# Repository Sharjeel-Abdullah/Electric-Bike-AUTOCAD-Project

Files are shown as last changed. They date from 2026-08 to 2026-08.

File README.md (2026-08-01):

# Electric-Bike-AUTOCAD-Project
Complete engineering layout, CAD drawing files, and manufacturing cost analysis for a 2 kW Electric Bike assembly.
# Electric Bike Assembly Design

A complete CAD assembly, mechanical layout, and cost analysis for a commuter electric bike designed in **AutoCAD**.

---

## 📌 Features & Contents

* **AutoCAD Assembly:** Complete 2D/3D `.dwg` drawings for the chassis, motor mounts, and component packaging.
* **Cost Estimation:** Itemized Bill of Materials (BOM) including component pricing and material selection.
* **Design Renders:** Visual preview sheets and exported CAD renders for quick viewing.

---

## 📁 Repository Structure

```text
--> README.md               # Project documentation
--> Electric Bike Project   # Whole Project
  -->Assembly               # Contains the AUTOCAD File + Screenshots to preview the project
  -->Documentation          # Complete Report + Cost Estimation

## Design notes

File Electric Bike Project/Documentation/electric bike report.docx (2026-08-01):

DESIGN AND DEVELOPMENT OF

ELECTRIC BIKE

[Project Report]

ABSTRACT

The increasing demand for sustainable transportation, rising fuel costs and growing environmental concerns have accelerated the development of electric vehicles as an efficient alternative to conventional fuel-powered transportation. This project presents the design and development of an Electric Bike that provides an economical, environment friendly and energy-efficient solution for short and medium-distance travel purpose. The proposed system integrates a Brushless DC (BLDC) motor powered by a lithium-ion battery pack, offering high efficiency, low maintenance and reliable performance.

The electric bike is designed with a lightweight yet durable frame that accommodates the battery pack, motor, controller, and other essential electrical components while maintaining proper weight distribution and rider comfort. A high-performance BLDC motor is selected to deliver smooth acceleration and a maximum speed suitable for urban transportation. The lithium-ion battery provides sufficient energy storage to achieve an extended driving range on a single charge while reducing charging frequency and operating costs.

The vehicle incorporates an LCD display that provides real-time information, including speed, battery level, trip distance and other operational parameters, enabling the rider to monitor the system effectively. For enhanced safety, the bike is equipped with Brembo hydraulic disc brakes, providing reliable braking performance under various riding conditions. The suspension system consists of hydraulic telescopic front forks and adjustable rear shock absorbers, ensuring improved ride comfort, vehicle stability and effective vibration damping on uneven road surfaces.

The design process includes component selection, system modeling, mechanical layout, electrical integration and performance analysis to ensure efficient operation and structural reliability. The completed design demonstrates the practical application of electric vehicle technology by combining efficiency, safety, durability, and rider comfort within a compact two-wheeled platform. This project highlights the potential of electric bikes as a sustainable mode of transportation capable of reducing fuel consumption, lowering greenhouse gas emissions and minimizing maintenance costs while meeting the daily mobility requirements of modern society.

TABLE OF CONTENTS:

Sr No. | TOPICS | Page No.
1. | OBJECTIVES | 4
2. | PROBLEMS | 5-6
3. | PROPOSED SOLUTIONS | 7-10
4. | COMPONENTS AND MATERIALS USED WITH SPECIFICATIONS | 10-16
5. | DESIGN CALCULATIONS | 17-23
6. | FABRICATION PROCESS | 23
7. | ASSEMBLY PROCESS | 23
8. | WORKING PRINCIPLE | 24
9. | COST ESTIMATION | 24-25
10. | LIMITATIONS OF THE PROPOSED MODEL | 25-26
11. | CONCLUSION | 26
12. | CAD MODEL AND ASSEMBLY | 27-28
13. | REFERENCES | 29

1) Objectives
- Design and develop an electric bike capable of safely carrying two adult riders with a strong and durable frame.
- Select a 2 kW BLDC motor and a 60 V lithium-ion battery to achieve a maximum speed of approximately 50 km/h with efficient power delivery.
- Integrate an efficient electrical drive system comprising the BLDC motor, motor controller, battery management system (BMS), and throttle for smooth and reliable operation.
- Equip the bike with a multifunction LCD display to provide real-time information such as speed, battery level, and trip distance.
- Enhance rider safety by incorporating Brembo hydraulic disc brakes and a hydraulic suspension system for superior braking performance and riding comfort.
- Evaluate the bike's performance in terms of speed, load-carrying capacity, battery range, structural stability, and overall efficiency to ensure compliance with the design objectives.
2) PROBLEMS

The transportation sector is one of the largest contributors to fuel consumption and environmental pollution. Conventional fuel-powered motorcycles, although widely used, suffer from several drawbacks related to efficiency, operating cost, and environmental impact. Likewise, many existing electric bikes available in the market utilize low-cost components that compromise performance, reliability, and rider comfort. These limitations motivated the development of the proposed electric bike using an optimized combination of modern electrical and mechanical components.

Problems Associated with Fuel-Based Motorcycles

1. High Fuel Consumption

Conventional motorcycles rely on petrol or diesel, whose prices continue to increase over time. Daily commuting results in significant fuel expenses, making transportation costly for users.

2. Environmental Pollution

Internal combustion engines emit harmful gases such as carbon dioxide (CO₂), carbon monoxide (CO), nitrogen oxides (NOₓ), and unburned hydrocarbons, contributing to global warming and air pollution.

3. High Maintenance Requirements

Fuel-powered engines consist of numerous moving parts that require regular servicing, including engine oil replacement, spark plug maintenance, clutch adjustments, air filter cleaning, and exhaust system servicing.

4. Low Energy Efficiency

A large portion of the fuel's energy is lost as heat through the engine and exhaust system, resulting in comparatively lower overall efficiency than electric propulsion systems.

5. Noise and Vibration

Combustion engines generate considerable noise and vibration, reducing rider comfort and contributing to noise pollution in urban environments.

6. Dependence on Fossil Fuels

Fuel-powered motorcycles rely entirely on non-renewable fossil fuels, making them unsustainable as fuel resources continue to diminish.

Problems Found in Many Existing Electric Bikes

Although electric bikes eliminate many of the disadvantages of fuel-powered motorcycles, several commercially available low-cost electric bikes still exhibit notable limitations.

1. Use of Brushed DC Motors

Many entry-level electric bikes employ brushed DC motors due to their lower initial cost. However, these motors have brushes that wear over time, require frequent maintenance, generate heat, and operate with lower efficiency.

2. Lead-Acid Batteries

Some electric bikes continue to use lead-acid batteries because of their low purchase price. These batteries are heavy, have lower energy density, longer charging times, shorter service life, and provide limited travel range.

3. Basic Mechanical Braking Systems

Low-cost electric bikes often use mechanical drum or cable-operated disc brakes, which offer lower braking performance and require frequent adjustment compared to hydraulic braking systems.

4. Conventional Suspension Systems

Basic spring suspension provides limited vibration damping and reduced comfort, especially when traveling on uneven roads or carrying additional load.

5. Lack of Smart Monitoring

Many economical electric bikes lack digital displays, preventing riders from monitoring battery percentage, speed, trip distance, and system status accurately.

6. Reduced Performance

The combination of low-capacity batteries and lower-efficiency motors often results in reduced acceleration, lower maximum speed, and shorter travel distance per charge.

3) PROPOSED SOLUTION

To overcome the limitations of conventional motorcycles and existing electric bikes, the proposed electric bike incorporates a carefully selected combination of electrical and mechanical components that improve efficiency, safety, reliability, and rider comfort.

1. BLDC Motor Instead of a Brushed DC Motor

A Brushless DC (BLDC) motor is selected as the propulsion system due to its superior performance and efficiency.

Brushed DC Motor | BLDC Motor (Selected)
Brushes wear out with time | Brushless construction eliminates wear
Requires regular maintenance | Virtually maintenance-free
Lower efficiency | Higher efficiency (typically 85–95%)
Generates more heat | Better thermal performance
Shorter lifespan | Longer operational life
Lower torque | Higher torque-to-weight ratio

Reason for Selection:
The BLDC motor offers higher efficiency, smoother operation, reduced maintenance, and longer service life, making it ideal for electric vehicles.

2. Lithium-Ion Battery Instead of Lead-Acid Battery

The proposed bike uses a Lithium-Ion battery pack rather than a lead-acid battery.

Lead-Acid Battery | Lithium-Ion Battery (Selected)
Heavy | Lightweight
Lower energy density | Higher energy density
Shorter lifespan | Longer cycle life
Slow charging | Faster charging
Higher maintenance | Maintenance-free
Lower travel range | Greater travel range

Reason for Selection:
Lithium-ion batteries significantly reduce vehicle weight while increasing range, charging efficiency, and overall battery life.

3. Hydraulic Brembo Disc Brakes Instead of Mechanical Brakes

For the braking system, Brembo hydraulic disc brakes are employed.

Mechanical Brakes | Brembo Hydraulic Disc Brakes (Selected)
Higher braking effort | Lower lever effort
Less precise braking | Excellent braking control
Requires cable adjustment | Self-adjusting hydraulic system
Reduced stopping performance | Superior stopping power

Reason for Selection:
Hydraulic disc brakes provide shorter stopping distances, improved safety, and consistent braking performance in both dry and wet conditions.

4. Hydraulic Suspension Instead of Conventional Spring Suspension

The proposed bike utilizes hydraulic telescopic front forks and adjustable rear hydraulic shock absorbers.

Conventional Suspension | Hydraulic Suspension (Selected)
Limited damping | Excellent vibration damping
Reduced comfort | Improved ride comfort
Less stability | Better handling and stability
Lower adaptability | Adjustable for varying road conditions

Reason for Selection:
Hydraulic suspension enhances rider comfort, minimizes vibration, and improves vehicle stability across different terrains.

5. LCD Display Instead of Analog Indicators

The bike is equipped with a modern LCD display.

Analog Meter | LCD Display (Selected)
Limited information | Multiple real-time parameters
Difficult to monitor battery | Accurate battery monitoring
No trip information | Trip and odometer functions
No fault indication | Diagnostic and warning indicators

Reason for Selection:
The LCD display provides comprehensive real-time information, enabling better rider awareness and efficient battery management.

4) Materials and Components Used and Specifications

4.1. Frame and Chassis

Parameter | Specification
Material | Mild Steel (AISI 1018 / ASTM A36)
Manufacturing Process | MIG Welding
Shape | Rectangular & Circular Hollow Sections
Wall Thickness | 2.5–3 mm
Factor of Safety | ≥ 2

Reason for Selection:

- High structural strength
- Good weldability
- Economical
- Easily available
- Suitable for carrying two adults

4.2. Electric Motor

Parameter | Specification
Type | Brushless DC (BLDC) Hub Motor
Rated Power | 2000 W (2 kW)
Rated Voltage | 60 V
Peak Torque | 70–80 Nm
Rated Speed | 650–700 RPM
Maximum Vehicle Speed | ≈ 50 km/h
Cooling | Air Cooled
Efficiency | 88–92%

Reason for Selection:

- High efficiency
- Maintenance-free
- High starting torque
- Long service life

4.3. Battery Pack

Parameter | Specification
Type | Lithium-Ion
Voltage | 60 V
Capacity | 30 Ah
Energy | 1800 Wh (1.8 kWh)
Cell Type | 18650 or 21700 Lithium-Ion Cells
Battery Management System | Integrated BMS
Charging Time | 5–6 Hours

Estimated Range

Approximately 60–70 km per full charge

4.4. Motor Controller

Parameter | Specification
Type | BLDC Controller
Rated Voltage | 60 V
Current Rating | 40–45 A
Control Method | PWM
Protection | Over-current, Over-voltage, Under-voltage, Short Circuit

4.5. Battery Management System (BMS)

Parameter | Specification
Battery Compatibility | 60 V Lithium-Ion
Continuous Current | 45 A
Functions | Cell Balancing, Over-charge Protection, Over-discharge Protection, Short Circuit Protection

4.6. Throttle

Parameter | Specification
Type | Hall Effect Twist Throttle
Operating Voltage | 5 V
Output Signal | 1–4 V

4.7. Display

Parameter | Specification
Type | LCD Display
Display Functions | Speed, Battery Percentage, Odometer, Trip Meter, Voltage, Error Codes
Backlight | LED

4.8. Braking System

Parameter | Specification
Brand | Brembo
Type | Hydraulic Disc Brakes
Front Disc | 220 mm
Rear Disc | 220 mm
Brake Fluid | DOT 4

4.9. Front Suspension

Parameter | Specification
Type | Hydraulic Telescopic Fork
Travel | 120 mm
Material | High Strength Steel

4.10. Rear Suspension

Parameter | Specification
Type | Adjustable Hydraulic Mono Shock
Travel | 100 mm
Spring Type | Coil Spring

4.11. Wheels

Parameter | Specification
Material | Cast Aluminum Alloy
Diameter | 17 inches
Rim Type | Alloy

4.12. Tires

Parameter | Specification
Front Tire | 90/90–17
Rear Tire | 100/80–17
Type | Tubeless Radial

4.13. Handlebar

Parameter | Specification
Material | Aluminum Alloy
Width | 400 mm

4.14. Seat

Parameter | Specification
Type | Dual Rider Seat
Cushion Material | High Density PU Foam
Cover Material | Waterproof Leatherette

4.15. Lighting System

Parameter | Specification
Headlight | LED
Tail Light | LED
Turn Indicators | LED
Brake Light | LED

4.16. Charger

Parameter | Specification
Type | Smart Lithium-Ion Charger
Input | 220–240 VAC
Output | 67.2 V DC
Charging Current | 5 A

4.17. Wiring

Parameter | Specification
Material | Copper
Insulation | PVC
Wire Gauge | 10–18 AWG (depending on load)

4.18. Fasteners

Parameter | Specification
Material | Stainless Steel (Grade 304)
Bolt Grade | 8.8 High Tensile

4.19. Bearings

Parameter | Specification
Type | Deep Groove Ball Bearings
Material | Chrome Steel

20. Side Stand

Parameter | Specification
Material | Mild Steel
Finish | Powder Coated

5) Design Calculations

5.1 Design Parameters

The following design parameters are considered throughout the analysis.

PARAMETER | SYMBOL | VALUE
Vehicle Weight | Wb | 60 kg
Rider Weight (2 persons) | Wr | 140 kg
Total Weight | M | 200kg
Maximum Speed | V | 50 km/h (13.89 ms)
Wheel Diameter | D | 0.50 m
Wheel Radius | R | 0.25 m
Battery Voltage | Vb | 60 V
Battery Capacity | C | 30 Ah
Motor Efficiency | Η | 90 %

5.2 Total Vehicle Load

The total design load is

m=W_b +W_r m=60+140 m=200 kg

This load is used for selecting the motor, frame, suspension and braking system.

5.3 Wheel Rotational Speed

Wheel circumference

C=πD C=3.1416×0.50 C=1.57 m

Vehicle speed

V=50 km/h Convert to m/s

V=(50×1000)/3600 V=13.89 m/s

Wheel RPM

RPM=(V×60)/C RPM=(13.89×60)/1.57 RPM≈531

Therefore, the selected BLDC motor should provide approximately 530–600 RPM.

5.4 Required Traction Force

Rolling resistance coefficient

C_(rr) =0.015

Normal force

N=mg N=200×9.81 N=1962 N

Rolling resistance

F_r =C_(rr) N F_r =0.015×1962 F_r =29.4 N

Considering aerodynamic drag and acceleration,

Total tractive force
F_t ≈120 N

5.5 Motor Power Requirement

Power is

P=F×V P=120×13.89 P=1667 W

Including transmission losses and safety factor

P_(required) =1667×1.2 P_(required) ≈2000 W

Therefore, Selected Motor : 2 kW BLDC Hub Motor

5.6 Motor Torque Calculation

Power equation

P=(2πNT)/60

Rearranging

T=(60P)/(2πN)

Where

P = 2000 W

N = 550 RPM

T=(60×2000)/(2×3.1416×550) T=34.7 Nm

A hub motor with peak torque of 70–80 Nm is therefore suitable.

5.7 Battery Capacity

Battery Energy

E=V×Ah E=60×30 E=1800 Wh

or

1.8 kWh

5.8 Battery Current

Motor Current

I=P/V I=2000/60 I=33.3 A

A controller rated

40–45 A

is selected.

5.9 Estimated Driving Range

Typical energy consumption

30 Wh/km

Range

Range=(Battery Energy)/(Energy Consumption) Range=1800/30 Range=60 km

Estimated driving range

≈ 60 km per full charge

5.10 Battery Charging Time

Charging current

5 A

Battery Capacity

30 Ah

Charging time

t=(Capacity)/(Charging Current) t=30/5 t=6 hours

Considering charging losses

Charging Time≈6-7 hours

5.11 Braking Force

Desired deceleration

a=5 m/s^2

Braking force

F=ma F=200×5 F=1000 N

Hence,

Brembo hydraulic disc brakes are selected to safely generate the required braking force.

5.12 Suspension Load

Assuming

Front Load 40 %

Rear Load 60 %

Front Suspension:

0.40×200 80 kg

Rear Suspension:

0.60×200 120 kg

Thus,

Hydraulic telescopic front forks and adjustable rear hydraulic shock absorbers are selected.

5.13 Frame Design Load

Maximum Design Load

200 kg

Factor of Safety

FOS=2

Design Load

200×2 400 kg

Therefore, the chassis should safely withstand an equivalent static load of 400 kg, justifying the use of AISI 1018/1020 mild steel tubing with adequate wall thickness.

6.1 Fabrication Process

The fabrication of the electric bike began with the construction of the frame using AISI 1018 mild steel tubes which were cut to the required dimensions and joined using MIG welding. After welding, the frame will be inspected for dimensional accuracy and structural integrity before being cleaned and finished. Mounting points for the BLDC motor, lithium-ion battery pack, controller, suspension system33 and braking components were incorporated into the frame to ensure proper alignment and secure installation. The fabricated frame was then prepared for final assembly.

6.2 Assembly Process

The assembly process involves mounting the 2 kW BLDC hub motor to the rear wheel, followed by the installation of the 60 V lithium-ion battery pack, motor controller, and Battery Management System (BMS). The front telescopic forks, rear hydraulic shock absorbers, Brembo hydraulic disc brakes, wheels, handlebars and seat were then assembled onto the frame. The electrical wiring, throttle, LCD display, lighting system and charging port are connected according to the circuit design. Finally, all mechanical and electrical connections were inspected, tightened, and tested to ensure the electric bike operated safely and efficiently.

Working Principle:

The proposed electric bike operates by converting electrical energy stored in the lithium-ion battery into mechanical energy through a Brushless DC (BLDC) motor. When the rider turns the ignition switch ON and applies the throttle, a signal is sent to the motor controller. The controller regulates the power supplied from the battery to the BLDC motor according to the throttle input, allowing smooth acceleration and speed control. The rotating motor drives the rear wheel, propelling the bike forward.

During operation, the Battery Management System (BMS) continuously monitors the battery voltage, current, and temperature to ensure safe and efficient performance while protecting the battery from overcharging, over-discharging, and overcurrent conditions. The LCD display provides real-time information such as vehicle speed, battery state of charge, and trip distance, enabling the rider to monitor the operating status of the bike. The hydraulic telescopic front forks and rear hydraulic shock absorbers absorb road irregularities, improving ride comfort and stability, while the Brembo hydraulic disc brakes provide reliable braking performance for safe deceleration and stopping. The integrated operation of these electrical and mechanical systems ensures efficient, safe, and environmentally friendly transportation for two riders.

Cost Estimation

The estimated manufacturing cost of the proposed electric bike is based on the prices of commercially available components and standard fabrication charges. The values presented are approximate and may vary depending on the supplier, component quality, and manufacturing location.

- Frame and chassis fabrication (AISI 1018 Mild Steel): Approximately PKR 35,000
- BLDC Hub Motor (2 kW): Approximately PKR 70,000
- Lithium-Ion Battery Pack (60 V, 30 Ah): Approximately PKR 95,000
- BLDC Motor Controller: Approximately PKR 12,000
- Battery Management System (BMS): Approximately PKR 8,000
- LCD Display: Approximately PKR 5,000
- Hall-Effect Throttle: Approximately PKR 2,000
- Brembo Hydraulic Disc Brake Set: Approximately PKR 28,000
- Hydraulic Telescopic Front Suspension: Approximately PKR 18,000
- Rear Hydraulic Shock Absorbers: Approximately PKR 15,000
- 17-inch Alloy Wheels: Approximately PKR 18,000
- Tubeless Tires: Approximately PKR 12,000
- Handlebar Assembly: Approximately PKR 5,000
- Dual Rider Seat: Approximately PKR 6,000
- LED Lighting System (Headlight, Tail Light & Indicators): Approximately PKR 6,000
- Smart Battery Charger: Approximately PKR 10,000
- Electrical Wiring, Connectors and Switches: Approximately PKR 5,000
- Bearings, Fasteners and Miscellaneous Hardware: Approximately PKR 8,000
- Painting and Surface Finishing: Approximately PKR 8,000
- Assembly and Fabrication Labour: Approximately PKR 20,000

Based on the above estimates, the total manufacturing cost of the proposed electric bike is approximately PKR 386,000. If the design is manufactured on a commercial scale, the cost can be reduced through bulk procurement, optimized production processes, and economies of scale.

Limitations of the Proposed Model

The proposed electric bike has been designed using engineering calculations, CAD modeling, and component selection; however, certain limitations exist due to the scope of the project.

- The project is limited to the design and analysis stage, and a physical prototype has not been fabricated.
- The performance values presented in the report are predicted from engineering calculations and manufacturer specifications rather than experimental testing.
- The estimated driving range and maximum speed may vary depending on rider weight, road conditions, terrain, weather, and riding style.
- Structural strength and durability have been evaluated analytically; experimental fatigue and impact testing have not been performed.
- Battery life and charging performance are based on the selected battery specifications and may differ under practical operating conditions.
- The proposed design does not include advanced features such as regenerative braking, GPS navigation, anti-theft tracking, mobile application connectivity, or fast-charging capability.
- The cost estimation is approximate and may change due to fluctuations in market prices, manufacturing methods, and component availability.
- Prototype fabrication and comprehensive road testing are required before the design can be considered for commercial production or mass manufacturing.

These limitations indicate that the proposed model demonstrates the technical feasibility of the electric bike design, while future work should focus on prototype development, experimental validation, and performance optimization before commercialization.

Conclusion

This project presented the design and analysis of an Electric Bike as an efficient and environmentally friendly alternative to conventional fuel-powered motorcycles. The proposed design incorporates a 2 kW BLDC motor, 60 V lithium-ion battery, hydraulic suspension, Brembo hydraulic disc brakes, and an LCD display to achieve a maximum speed of approximately 50 km/h while safely carrying two adult riders.

The selection of components and engineering calculations indicate that the proposed design is capable of providing good performance, reliability, rider safety, and energy efficiency for urban transportation. Although the project is limited to the design stage and has not been physically fabricated or tested, the analytical results demonstrate the technical feasibility of the proposed electric bike. Future work should focus on prototype fabrication, experimental testing, and performance optimization to validate the design and prepare it for practical implementation and commercial production.

AutoCAD Model:

----------Orthographic Views----------

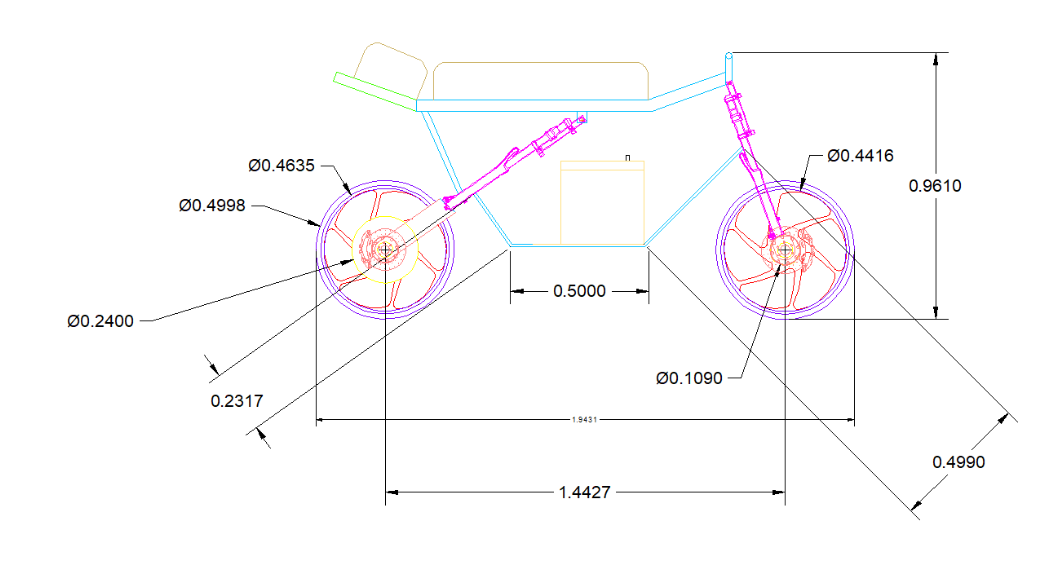
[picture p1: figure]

(Side View)

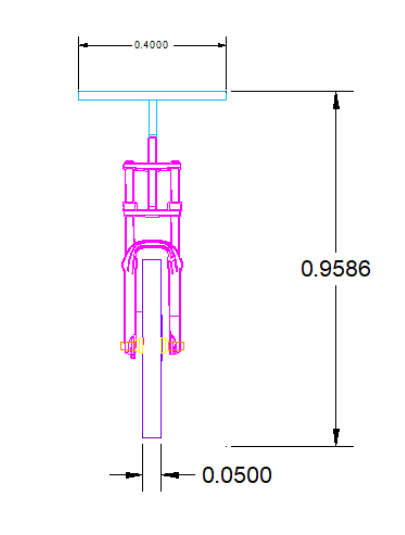
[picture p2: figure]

(Front View)

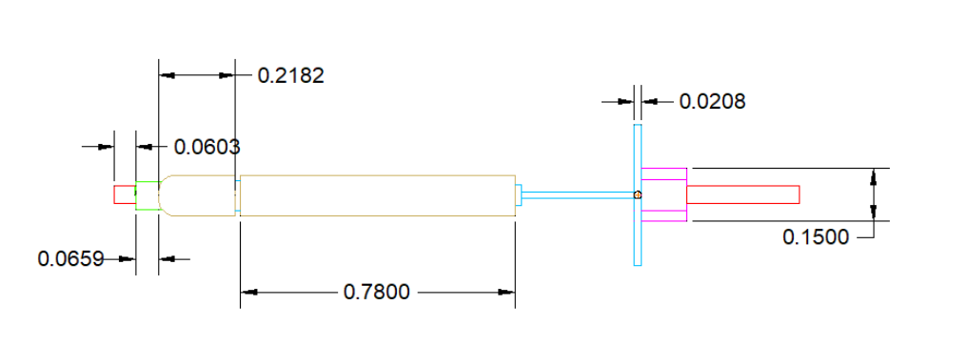
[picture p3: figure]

(Top View)

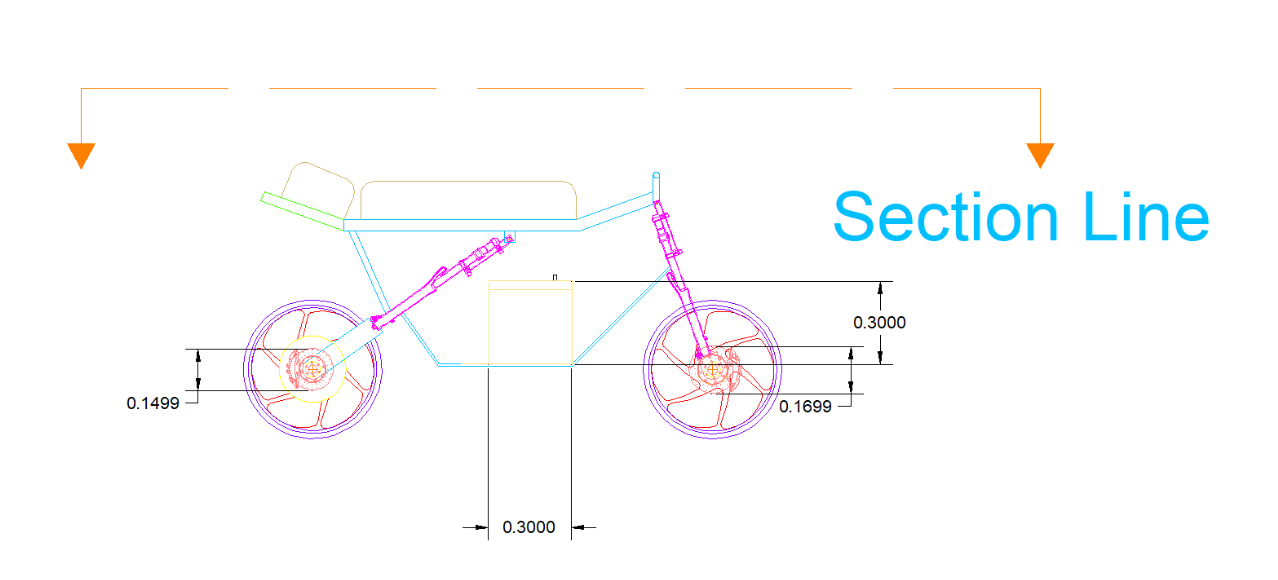
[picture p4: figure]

(Cutting Section Line)

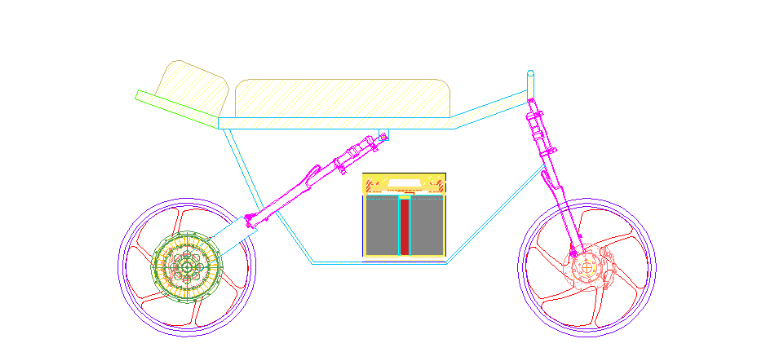
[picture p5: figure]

(Section View)

----------Assembly Views----------

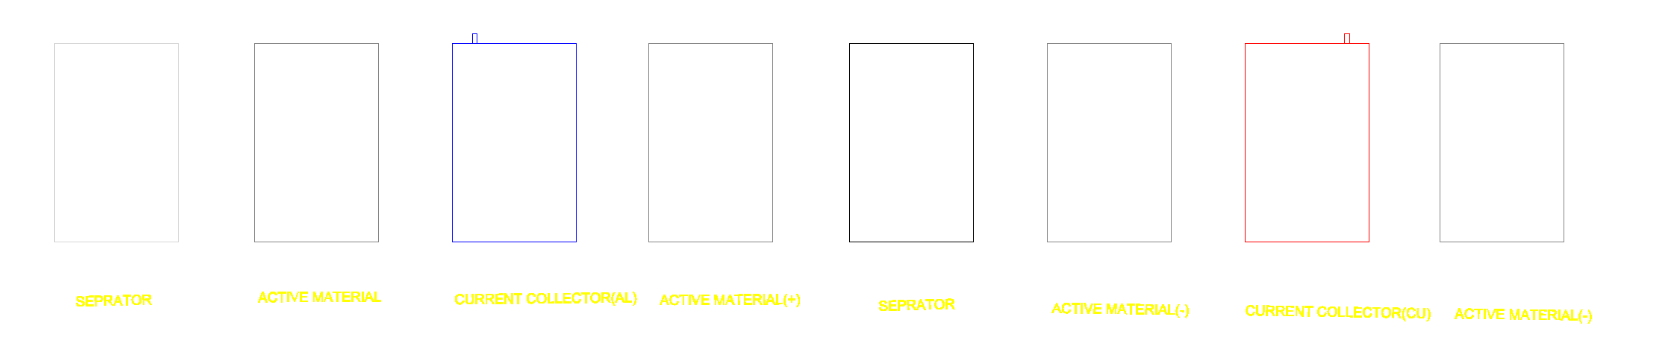
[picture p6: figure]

(Battery)

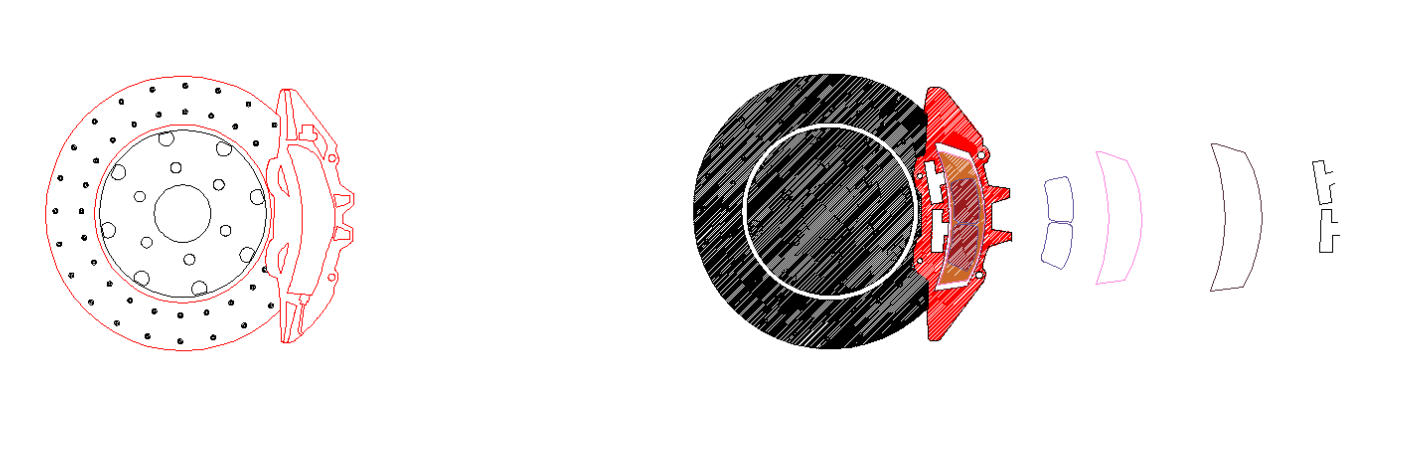
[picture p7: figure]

(Brembo Brakes)

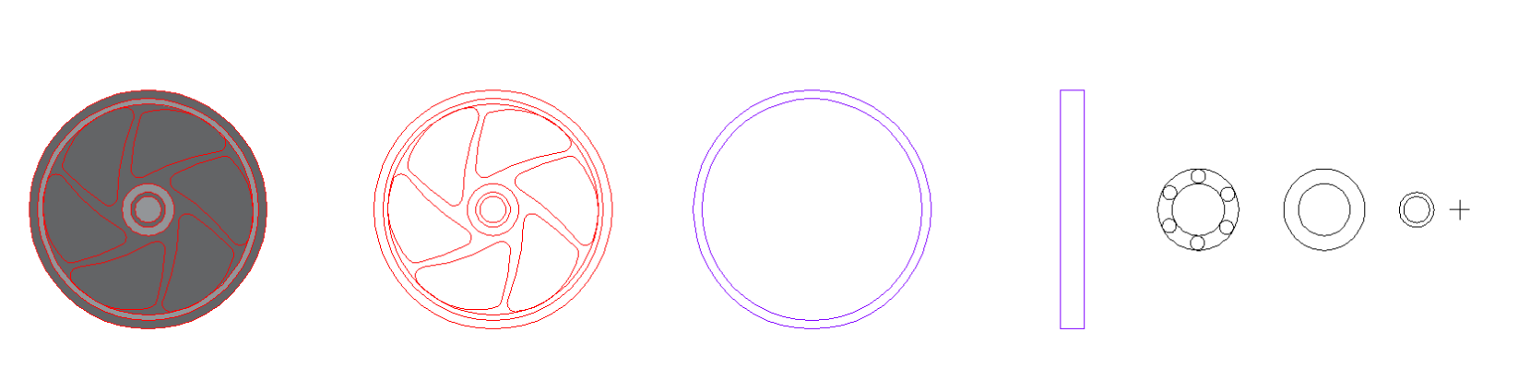
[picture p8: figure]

(Wheels - Tires, Rims and Axles)

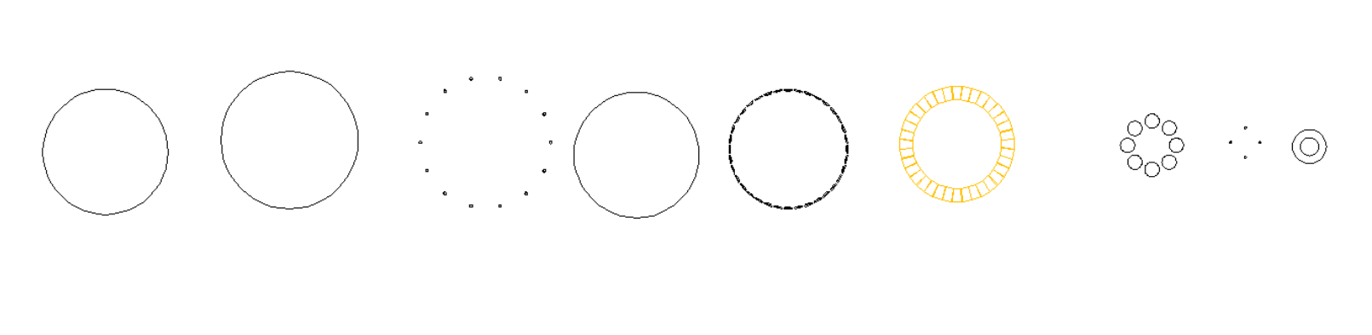
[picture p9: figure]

(BLDC Motor)

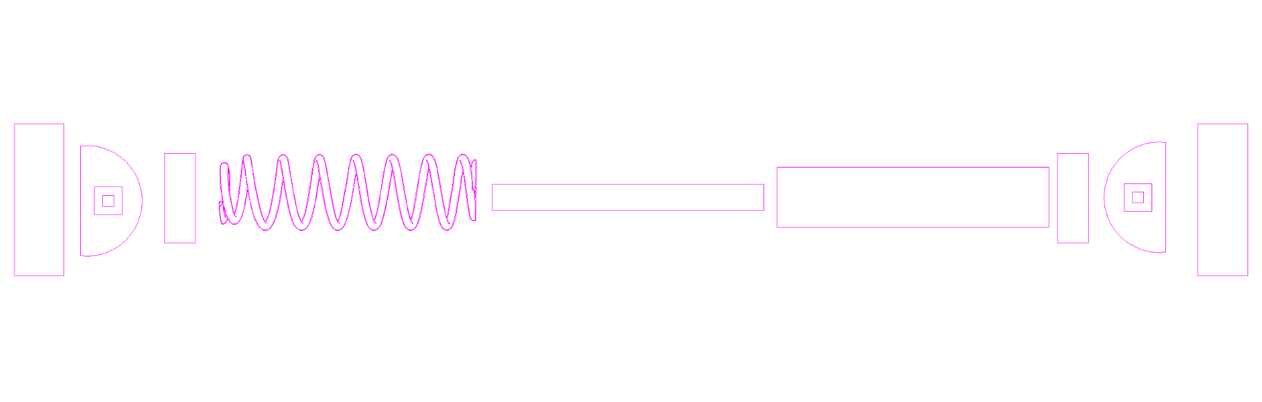
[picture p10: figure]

(Suspensions)

REFERENCES:

- https://www.brembo.com/en/solutions/for-original-equipement-bike/icons/stylema-caliper
- https://www.kyb.co.jp/en/products/motorcycle.html
- https://mechtex.com/blog/working-of-bldc-motor
- https://www.iqytechnicalcollege.com/BAE%20685-Electric%20Vehicle%20Technology.pdf
- https://www.sciencedirect.com/science/article/pii/S2352152X26008510?utm_source=chatgpt.com

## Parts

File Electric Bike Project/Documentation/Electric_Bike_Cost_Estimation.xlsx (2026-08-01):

Electric Bike Project - Cost Estimation
Estimated manufacturing and assembly bill of materials (PKR)
S.No | Item Description | Category | Estimated Cost (PKR)
1 | Frame & Chassis Fabrication (AISI 1018 Mild Steel) | Structure | 35000
2 | BLDC Hub Motor (2 kW) | Powertrain | 70000
3 | Lithium-Ion Battery Pack (60 V, 30 Ah) | Powertrain | 95000
4 | BLDC Motor Controller | Powertrain | 12000
5 | Battery Management System (BMS) | Powertrain | 8000
6 | LCD Display | Electronics | 5000
7 | Hall-Effect Throttle | Electronics | 2000
8 | Brembo Hydraulic Disc Brake Set | Brakes & Suspension | 28000
9 | Hydraulic Telescopic Front Suspension | Brakes & Suspension | 18000
10 | Rear Hydraulic Shock Absorbers | Brakes & Suspension | 15000
11 | 17-inch Alloy Wheels | Wheelset | 18000
12 | Tubeless Tires | Wheelset | 12000
13 | Handlebar Assembly | Controls & Body | 5000
14 | Dual Rider Seat | Controls & Body | 6000
15 | LED Lighting System (Headlight, Tail Light & Indicators) | Electronics | 6000
16 | Smart Battery Charger | Powertrain | 10000
17 | Electrical Wiring, Connectors and Switches | Electrical | 5000
18 | Bearings, Fasteners and Miscellaneous Hardware | Hardware | 8000
19 | Painting and Surface Finishing | Finishing | 8000
20 | Assembly and Fabrication Labour | Labor | 20000
 | Total Estimated Project Cost

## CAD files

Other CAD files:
Electric Bike Project/Assembly/Final drawing autocad completed.dwg

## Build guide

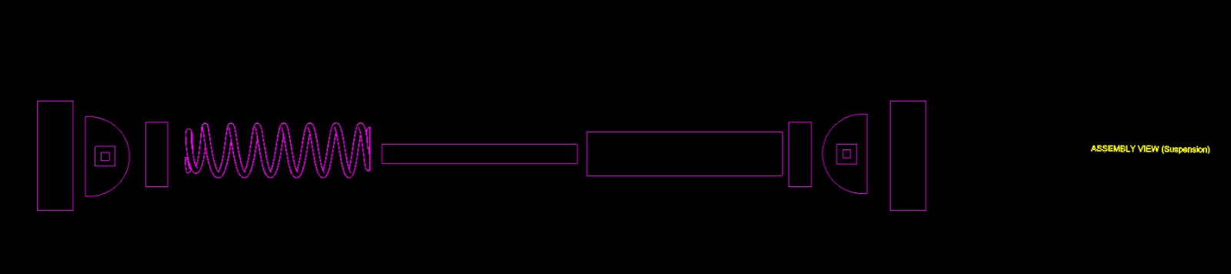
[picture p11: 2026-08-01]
Electric Bike Project/Assembly/Screenshots/Suspensions Assembly - Exploded View Electric Bike.jpeg

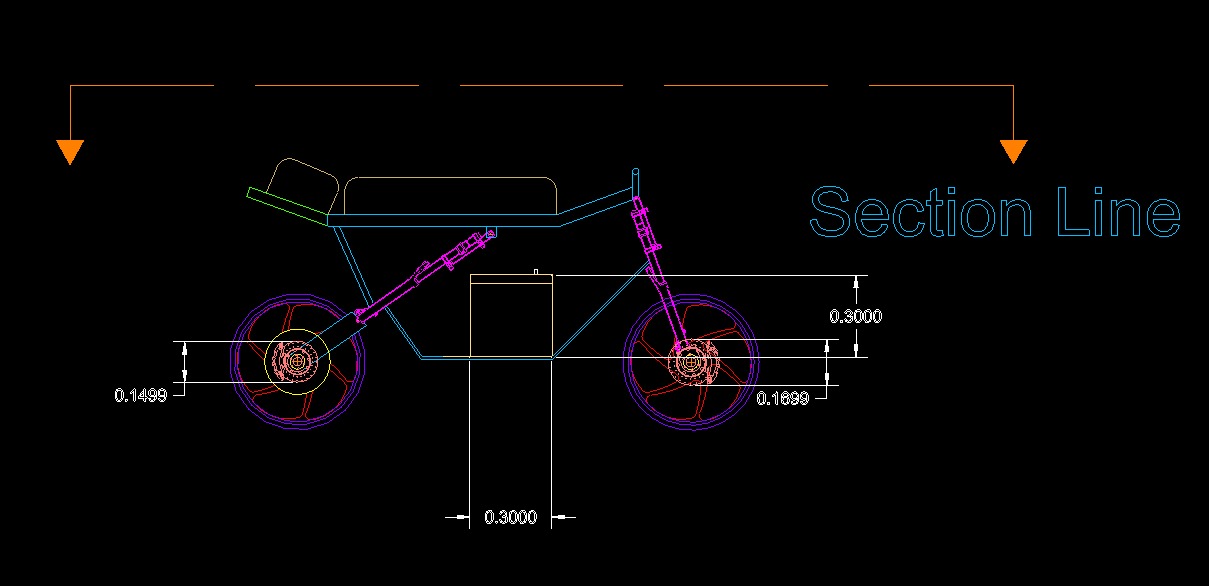
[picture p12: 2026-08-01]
Electric Bike Project/Assembly/Screenshots/Section Line Electric Bike.jpeg

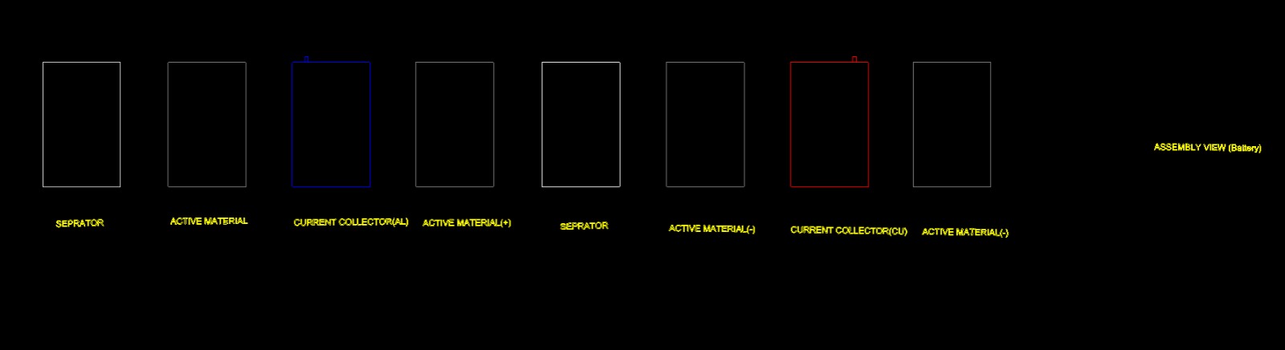
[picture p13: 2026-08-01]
Electric Bike Project/Assembly/Screenshots/Battery Assembly - Exploded View Electric Bike.jpeg

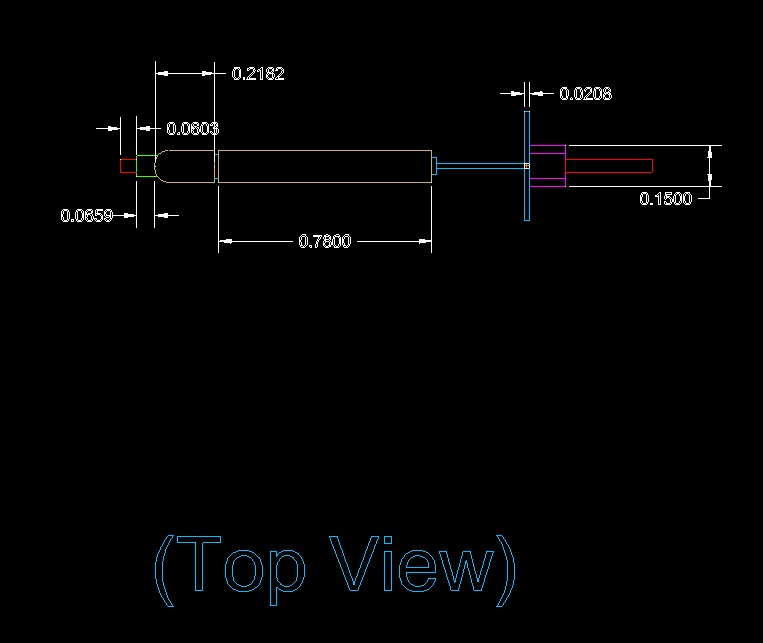
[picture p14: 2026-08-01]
Electric Bike Project/Assembly/Screenshots/Top View Electric Bike.jpeg

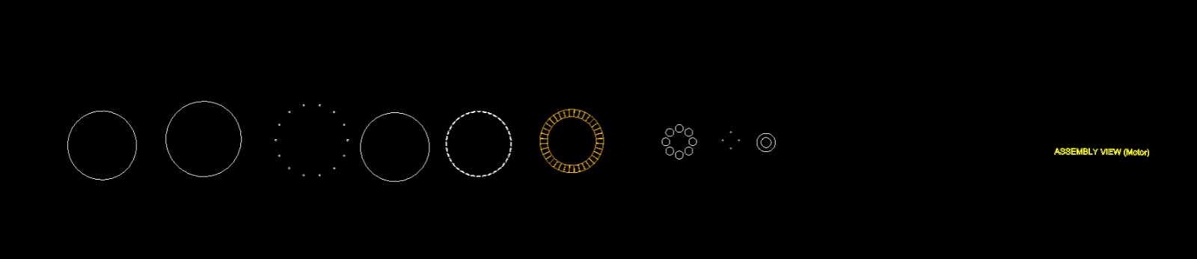
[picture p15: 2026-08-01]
Electric Bike Project/Assembly/Screenshots/BLDC Motor Assembly - Exploded View Electric Bike.jpeg

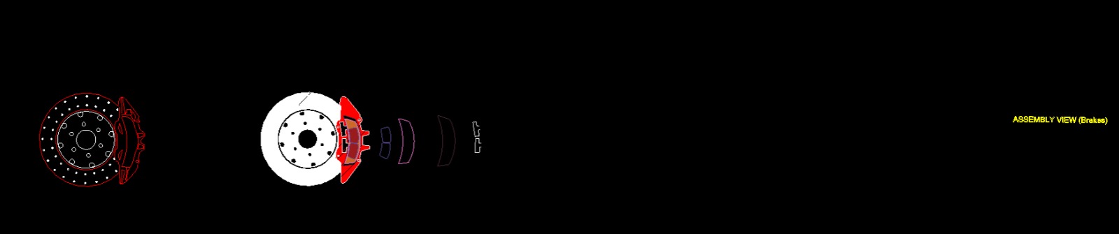
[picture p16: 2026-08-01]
Electric Bike Project/Assembly/Screenshots/Brembo Brakes Assembly - Exploded View Electric Bike.jpeg
